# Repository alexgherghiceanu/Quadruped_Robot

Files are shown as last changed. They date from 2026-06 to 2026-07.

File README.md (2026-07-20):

# Quadruped Robot
 
A Bluetooth-controlled spider robot powered by an STM32 microcontroller and written in Rust.
 
| | |
|---|---|
| **Author** | Alexandru-Bogdan Gherghiceanu |
| **University** | Politehnica București — Faculty of Automatic Control and Computer Science |
| **Course** | Microprocessor Architecture (PM), 2026 |
| **Project page** | [embedded-rust-101.wyliodrin.com](https://embedded-rust-101.wyliodrin.com/docs/acs_cc/project/2026/agherghiceanu) |
 
---
 
## Description
 
This project is a Bluetooth-controlled quadruped (spider) robot that pairs with your phone or tablet over BLE. Once connected, you can control its speed and direction of travel, and issue special commands such as making it wave. The robot uses 8 servomotors to produce smooth, natural movement.
 
## Motivation
 
A long-standing interest in robotics, combined with years of following Boston Dynamics' work, made a quadruped robot a natural project choice. After watching *Project Hail Mary*, a spider form factor felt like the perfect fit. The chassis is a modified version of the open-source [Sesame spider robot](https://www.doriantodd.com/sesame), adapted to accommodate the chosen components.
 
---
 
## Architecture
 
The system is organized into the following software modules running on the STM32:
 
```
Android/iOS Device
        │  (BLE)
        ▼
  HM-10 Bluetooth Module
        │  (UART / Serial)
        ▼
  Bluetooth Handler Module   ← parses commands (e.g. 'F', 'L', 'W')
        │
        ▼
  Motion Planner Module      ← determines target pose / leg positions (X, Y, Z)
        │
        ▼
  Kinematics Engine (IK)     ← converts positions to servo angles
        │
        ▼
  I2C Controller Module
        │  (I2C)
        ▼
  PCA9685 Servo Driver       ← generates PWM signals
        │
        ▼
  Servomotors x8
```
 
---
 
## Hardware
 
The brain of the robot is the **STM32 Nucleo-U545RE-Q** microcontroller. It receives Bluetooth commands via the HM-10 module (UART), computes the required servo positions, and sends them to a **PCA9685** 16-channel PWM driver over I2C. The driver then actuates the 8 **MG90S** servomotors (2 per leg). Power comes from a **7.4V 1000mAh 2S LiPo** battery, stepped down to the appropriate voltage for the logic and servos via an **XL4015** buck converter.

## Build Progress & Media

A look at the robot from early assembly to a working walking gait.

### Photos
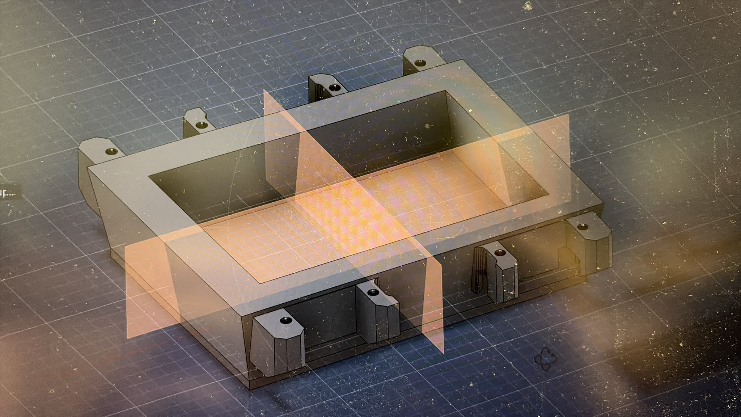
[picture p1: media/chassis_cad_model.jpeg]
CAD model of the chassis


| | |
|---|---|
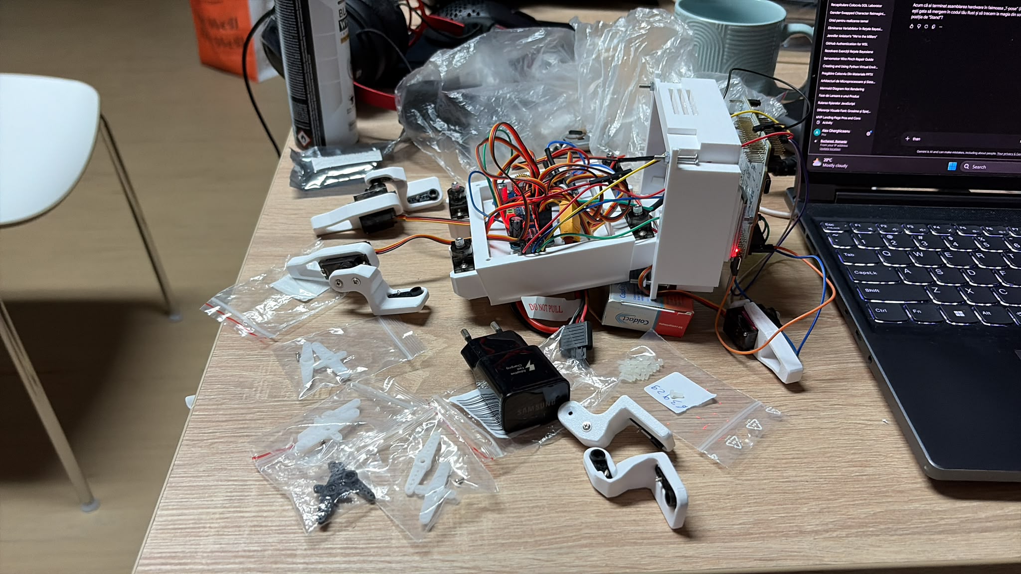
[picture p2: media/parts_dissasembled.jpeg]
Parts before assembly
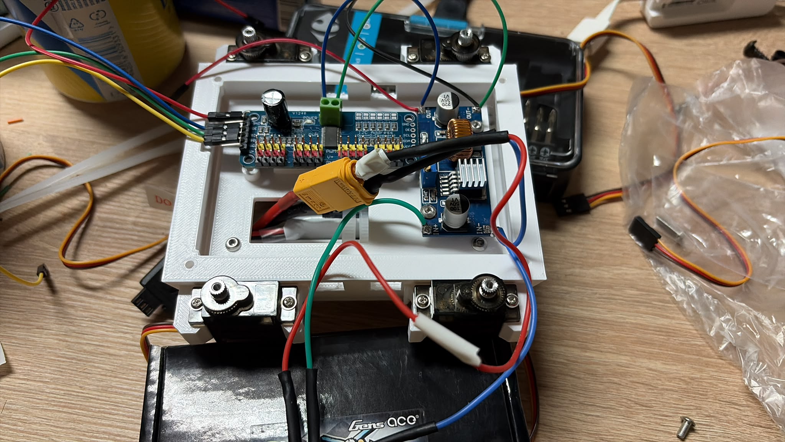
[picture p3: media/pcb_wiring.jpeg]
PCB and wiring
|  |  |
| Servos and parts before assembly | PCA9685 driver + power wiring |

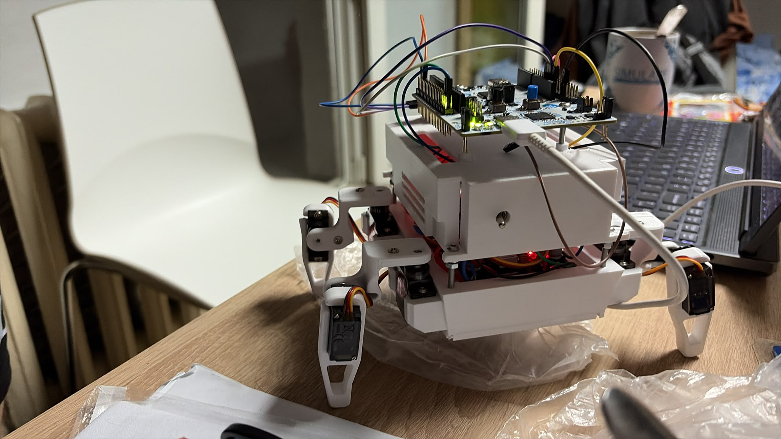
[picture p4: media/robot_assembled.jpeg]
Assembled robot


*The robot fully assembled, with the STM32 board mounted on top.*

### Demo

Walking demo
 
### Bill of Materials
 
| Component | Role | Price (RON) |
|---|---|---|
| STM32 Nucleo-U545RE-Q | Main microcontroller | ~120.00 |
| Servomotor MG90S (x8) | Leg actuation | 19.34 ea. |
| PCA9685 I2C 16-CH Servo Driver | Servo PWM interface | 27.27 |
| XL4015 Buck Converter (8-36V, 5A) | Voltage step-down | 9.96 |
| KCD-1 On/Off Switch | Power switch | 1.85 |
| HM-10 Bluetooth 4.0 Module | BLE communication | 29.99 |
| Electrolytic Capacitor 1000 uF 50V | Voltage buffering | 1.49 |
| 1K Ohm 0.25W Resistor | Signal conditioning | 0.10 |
| Undervoltage Battery Alarm | Low battery warning | 7.99 |
| B3 20W LiPo Charger (2S/3S) | Battery charging | 29.90 |
| Gens Ace 1000mAh 7.4V 30C 2S LiPo (XT60) | Main power source | 58.20 |
| XT60 Connector Set | Battery connection | 8.82 |
| Dupont F-F wires x10 (20cm) | Internal wiring | 2.67 |
| Dupont M-F wires x40 (20cm) | Internal wiring | 19.72 |
 
---
 
## Software
 
The firmware is written in **Rust** using the [Embassy](https://github.com/embassy-rs/embassy) async embedded framework.
 
| Library / Tool | Description | Usage |
|---|---|---|
| `embassy-stm32` | STM32 HAL | Controls board pins; drives PCA9685 via I2C and HM-10 via UART |
| `embassy-executor` | Async executor | Runs the main task loop, processes BLE commands, updates motor angles |
| `embassy-time` | Timekeeping & delays | Controls animation frame timing for walking gait; handles BLE read timeouts |
| `defmt` + `defmt-rtt` | Logging framework | Streams debug info and state changes to a connected laptop terminal |
| `panic-probe` | Panic handler | Captures crashes and prints backtraces for easier debugging |
| `probe-rs` | Flash & debug tool | Compiles, flashes, and runs firmware on the STM32 via `cargo run` |
 
### Building & Flashing
 
Requires a Rust toolchain with the `thumbv8m.main-none-eabihf` target and `probe-rs` installed.
 
```bash
# Add the target (once)
rustup target add thumbv8m.main-none-eabihf
 
# Build and flash
cargo run --release
```
 
---

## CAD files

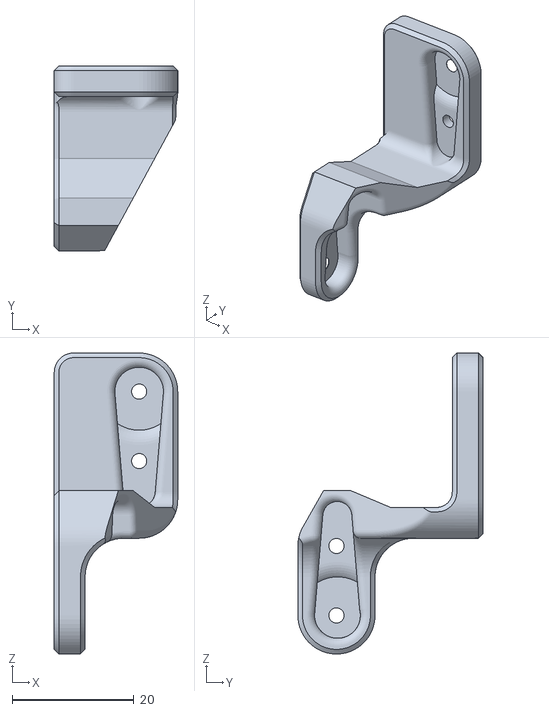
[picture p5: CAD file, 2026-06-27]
hardware/3D Files/R2-v117.stl
20.3 x 30.5 x 49.5

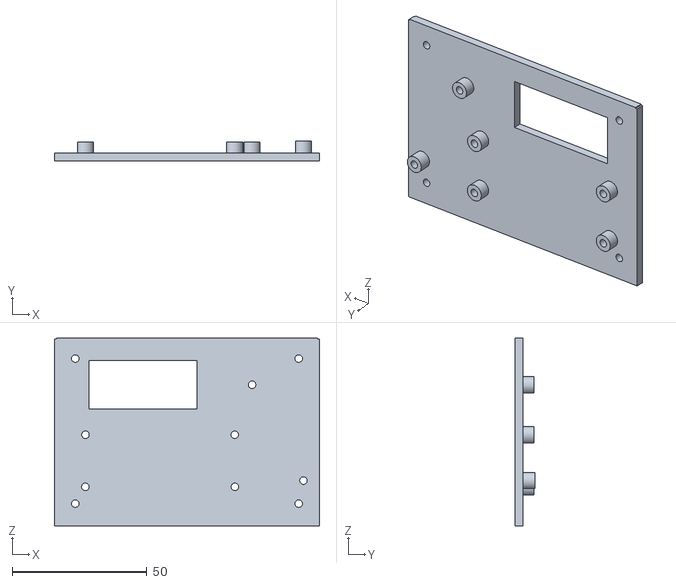
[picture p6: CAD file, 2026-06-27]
hardware/3D Files/cadru_intern_V3.stl
98.2 x 7.50 x 69.5

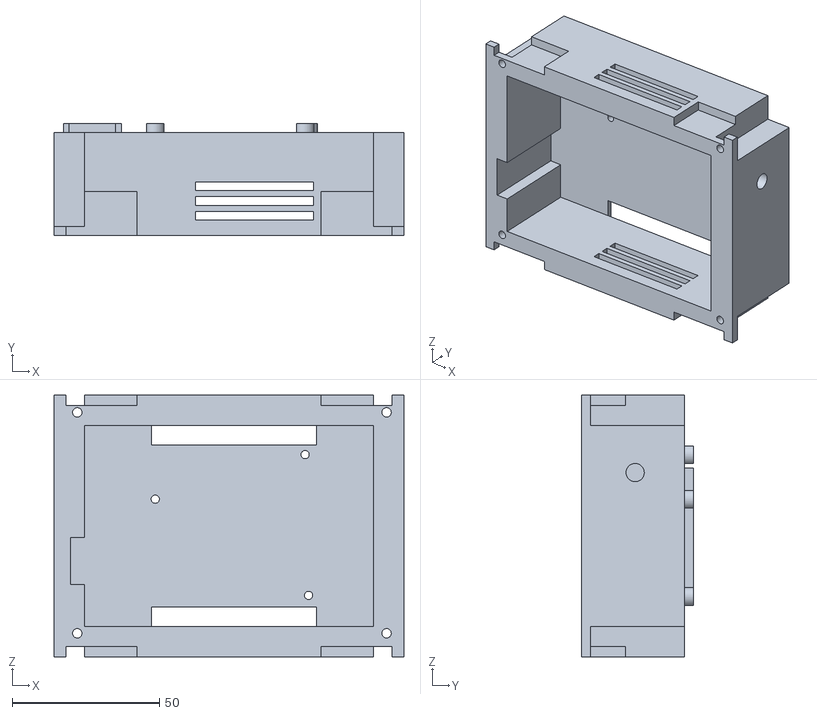
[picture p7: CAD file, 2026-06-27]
hardware/3D Files/cadru_nucleo+hm10.stl
118.8 x 38.0 x 88.8

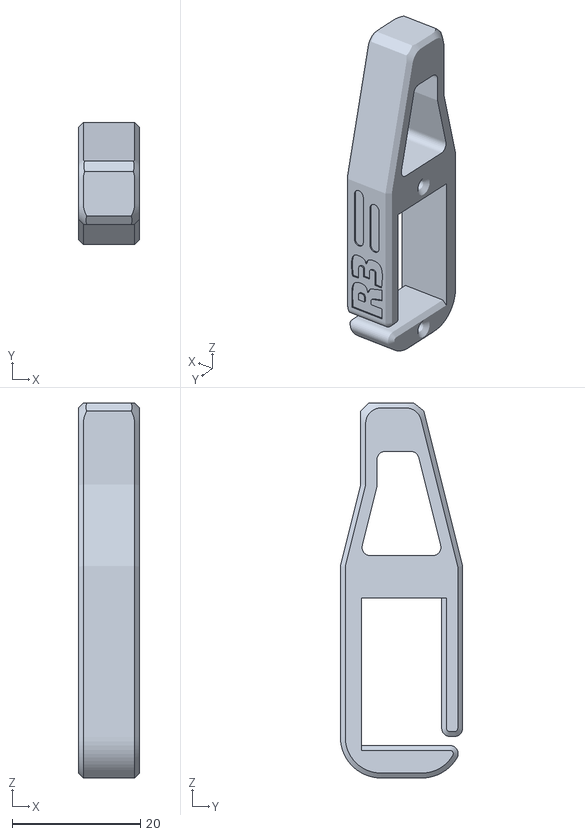
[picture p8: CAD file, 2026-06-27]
hardware/3D Files/R3-v117.stl
9.53 x 19.0 x 58.4

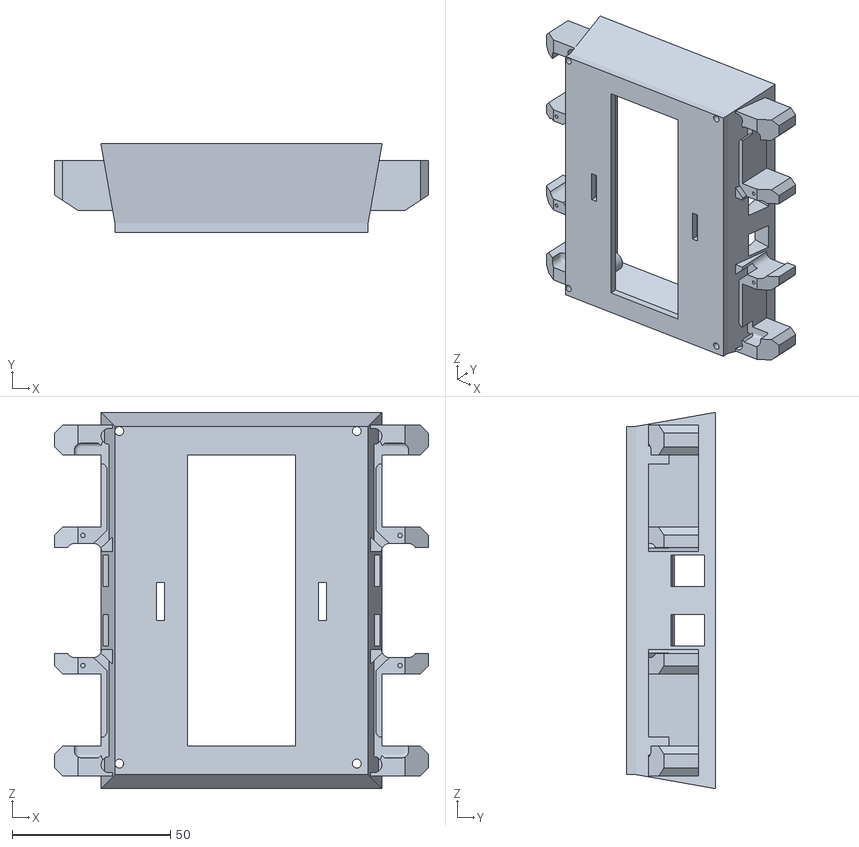
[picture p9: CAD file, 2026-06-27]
hardware/3D Files/baseplate_V2.stl
118.1 x 28.0 x 118.8

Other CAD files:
hardware/3D Files/L4-v117.stl
hardware/3D Files/L3-v117.stl
hardware/3D Files/L1-v117.stl
hardware/3D Files/L2-v117.stl
hardware/3D Files/R1-v117.stl
hardware/3D Files/R4-v117.stl

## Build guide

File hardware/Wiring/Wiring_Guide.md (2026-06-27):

## Wiring Guide
 
#### Power
 
The LiPo battery connects through the  on/off switch to the XL4015 buck converter `IN+` / `IN-`. Set the converter output to **5V** before connecting anything downstream. From the converter `OUT+` / `OUT-`, run power to two destinations: the **PCA9685** `V+` and `GND` rails (servo power), and the **STM32 Nucleo** `+5V` and `GND` pins.
 
#### HM-10 Bluetooth Module — UART
 
| HM-10 pin | STM32 pin |
|---|---|
| TXD (BT_RX net) | PA9 (BT_RX) |
| RXD (BT_TX net) | PA10 (BT_TX) |
| VCC | +5V |
| GND | GND |
 
Note the net labels cross as expected: the module's TX feeds the MCU's RX pin and vice versa.
 
#### PCA9685 Servo Driver  — I2C
 
| PCA9685 pin | STM32 pin |
|---|---|
| SCL | PB6 (I2C_SCL) |
| SDA | PB7 (I2C_SDA) |
| GND | GND |
| OE | GND (tie low to enable outputs) |
| VCC | +5V |
| V+ | +5V from buck converter |
 
VCC powers the PCA9685 logic and comes from the STM32 board and runs at 3.3V. V+ powers the servo rail runs at 5V here from the buck converter output.
 
#### Servomotors — PCA9685 outputs 
 
The 8 servos connect to the PCA9685. Each servo's signal wire maps to a PWM channel net.
 
Each servo connector is 3-pin: signal (PWM), VCC (+5V), GND. Power and ground for all servos come from the PCA9685 V+ and GND rails.

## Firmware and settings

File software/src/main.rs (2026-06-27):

#![no_std]
#![no_main]

use defmt::info;
use defmt_rtt as _;
use panic_probe as _;

use embassy_executor::Spawner;
use embassy_stm32::{bind_interrupts, peripherals, usart};
use embassy_stm32::i2c::{I2c, Config as I2cConfig};
use embassy_stm32::usart::{BufferedUart, Config as UartConfig};
use embassy_stm32::time::Hertz;
use embassy_time::{Duration, Timer, with_timeout};
use embedded_io_async::Read;

bind_interrupts!(struct Irqs {
    LPUART1 => usart::BufferedInterruptHandler<peripherals::LPUART1>;
});

#[derive(PartialEq)]
enum State {
    Stand,
    Forward,
    Backward,
    Left,
    Right,
    Debug,
    Wave
}

fn get_servo_buffer(angles: &[u8; 8]) -> [u8; 61] {
    let mut buf = [0u8; 61];
    buf[0] = 0x06; 

    const MIN_PULSE_US: u32 = 732;
    const MAX_PULSE_US: u32 = 2929;
    const PERIOD_US: u32 = 20000;

    let pca_pins: [usize; 8] = [0, 2, 4, 7, 8, 10, 12, 14];

    for i in 0..8 {
        let pin = pca_pins[i];
        let offset = 1 + pin * 4;
        
        let pulse = angles[i] as u32 * (MAX_PULSE_US - MIN_PULSE_US) / 180 + MIN_PULSE_US;
        let tick = ((pulse * 4096) / PERIOD_US) as u16;

        buf[offset] = 0;
        buf[offset + 1] = 0;
        buf[offset + 2] = (tick & 0xFF) as u8;
        buf[offset + 3] = (tick >> 8) as u8;
    }
    
    buf
}

#[embassy_executor::main]
async fn main(_spawner: Spawner) {
    let p = embassy_stm32::init(Default::default());
    

    info!("--- PLACA A PORNIT! INCEP INITIALIZAREA I2C ---");


    let mut i2c_config = I2cConfig::default();
    i2c_config.frequency = Hertz(100_000);
    let mut i2c = I2c::new_blocking(p.I2C1, p.PB6, p.PB7, i2c_config);
    let address = 0x40;

    info!("Pornire PCA9685...");
    let _ = i2c.blocking_write(address, &[0x00, 0x10]);
    let _ = i2c.blocking_write(address, &[0xFE, 121]);
    let _ = i2c.blocking_write(address, &[0x00, 0x20]);
    Timer::after_millis(10).await;

    let mut uart_config = UartConfig::default();
    uart_config.baudrate = 9600;
    
    static mut TX_STORAGE: [u8; 16] = [0; 16];
    static mut RX_STORAGE: [u8; 64] = [0; 64];

    let tx_buffer = unsafe { &mut *(&raw mut TX_STORAGE) };
    let rx_buffer = unsafe { &mut *(&raw mut RX_STORAGE) };
    
    let mut serial = BufferedUart::new(
        p.LPUART1, 
        p.PA3, // RX
        p.PA2, // TX
        tx_buffer, 
        rx_buffer, 
        Irqs, 
        uart_config
    ).unwrap();

    let mut state = State::Debug;
    let mut frame: usize = 0;
    let mut b = [0u8; 1]; 

    info!("Comenzi: W(Fata), S(Spate), A(Stanga), D(Dreapta), Q(Debug Montaj), E(Wave), T(Stand)");

    loop {
        if let Ok(Ok(_)) = with_timeout(Duration::from_millis(20), serial.read(&mut b)).await {
            let cmd = b[0] as char;
            match cmd {
                'W' | 'w' => { state = State::Forward; frame = 0; info!("FATA "); }
                'S' | 's' => { state = State::Backward; frame = 0; info!("SPATE "); }
                'A' | 'a' => { state = State::Left; frame = 0; info!("STANGA "); }
                'D' | 'd' => { state = State::Right; frame = 0; info!("DREAPTA "); }
                'Q' | 'q' => { state = State::Debug; frame = 0; info!("Debug Montaj (Toate la 90)"); }
                'E' | 'e' => { state = State::Wave; frame = 0; info!("Wave"); }
                'T' | 't' => { state = State::Stand; frame = 0; info!("Sta in picioare!"); }
                _ => {}
            }
        }

        match state {
            State::Stand => {
                                        // L1 ,L3, L2 ,L4, R1, R3, R2, R4
               let stand_pose = [90, 45,  90, 135, 90, 135,  90, 45]; 
                
                let buf = get_servo_buffer(&stand_pose);
                let _ = i2c.blocking_write(address, &buf);
            }
            State::Forward => {
                let frames = [
                    [110, 80,   70, 135,   110, 135,   110, 45],
                    [110, 45,   70, 135,   110, 135,   110, 45],

                    [110, 45,   70, 135,   110, 135,   70, 80],
                    [110, 45,   70, 135,   110, 135,   70, 45],

                    [110, 45,   70, 135,   70, 100,    70, 45],
                    [110, 45,   70, 135,   70, 135,    70, 45],

                    [110, 45,   110, 100,  70, 135,    70, 45],
                    [110, 45,   110, 135,  70, 135,    70, 45],

                    [70, 45,    70, 135,   110, 135,   110, 45],
                ];
                let buf = get_servo_buffer(&frames[frame]);
                let _ = i2c.blocking_write(address, &buf);
                
                frame += 1;
                if frame >= frames.len() {
                    frame = 0; 
                }
            }
            State::Backward => {
                let frames = [
                    [70, 80,   110, 135,  70, 135,   70, 45],
                    [70, 45,   110, 135,  70, 135,   70, 45],

                    [70, 45,   110, 135,  70, 135,   110, 80],
                    [70, 45,   110, 135,  70, 135,   110, 45],

                    [70, 45,   110, 135,  110, 100,  110, 45],
                    [70, 45,   110, 135,  110, 135,  110, 45],

                    [70, 45,   70, 100,   110, 135,  110, 45],
                    [70, 45,   70, 135,   110, 135,  110, 45],

                    [110, 45,  110, 135,  70, 135,   70, 45],
                ];
                let buf = get_servo_buffer(&frames[frame]);
                let _ = i2c.blocking_write(address, &buf);
                
                frame += 1;
                if frame >= frames.len() {
                    frame = 0; 
                }
            }
            State::Left => {
                let frames = [
                    [70, 80,   110, 135,  110, 135,  110, 45], 
                    [70, 45,   110, 135,  110, 135,  110, 45], 
                    
                    [70, 45,   110, 135,  110, 135,  70, 80], 
                    [70, 45,   110, 135,  110, 135,  70, 45], 
                    
                    [70, 45,   110, 135,  70, 100,   70, 45], 
                    [70, 45,   110, 135,  70, 135,   70, 45], 
                    
                    [70, 45,   70, 100,   70, 135,   70, 45], 
                    [70, 45,   70, 135,   70, 135,   70, 45], 
                    
                    [110, 45,  110, 135,  110, 135,  110, 45],
                ];
                let buf = get_servo_buffer(&frames[frame]);
                let _ = i2c.blocking_write(address, &buf);
                
                frame += 1;
                if frame >= frames.len() {
                    frame = 0;
                }
            }
            State::Right => {
                let frames = [
                    [110, 80,   70, 135,  70, 135,  70, 45], 
                    [110, 45,   70, 135,  70, 135,  70, 45], 
                    
                    [110, 45,   70, 135,  70, 135,  110, 80], 
                    [110, 45,   70, 135,  70, 135,  110, 45], 
                    
                    [110, 45,   70, 135,  110, 100, 110, 45], 
                    [110, 45,   70, 135,  110, 135, 110, 45], 
                    
                    [110, 45,   110, 100, 110, 135, 110, 45], 
                    [110, 45,   110, 135, 110, 135, 110, 45], 
                    
                    [70, 45,    70, 135,  70, 135,  70, 45],
                ];
                let buf = get_servo_buffer(&frames[frame]);
                let _ = i2c.blocking_write(address, &buf);
                
                frame += 1;
                if frame >= frames.len() {
                    frame = 0;
                }
            }
            State::Debug => {
                let buf = get_servo_buffer(&[90, 90, 90, 90,  90, 90, 90, 90]);
                let _ = i2c.blocking_write(address, &buf);
            }
            State::Wave => {
                let frames = [
                    [90, 125,   90, 135,   90, 135,   90, 65],

                    [90, 90,  90, 135,   90, 135,   90, 65],
                    
                    [90, 55,   90, 135,   90, 135,   90, 65],
                    
                    [90, 90,   90, 135,   90, 135,   90, 65],
                ];
                
                let buf = get_servo_buffer(&frames[frame]);
                let _ = i2c.blocking_write(address, &buf);
                
                frame += 1;
                if frame >= frames.len() { frame = 0; }
            }
        }

        Timer::after_millis(150).await;
    }
}

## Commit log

2026-06-27 Create Assembly Guide
2026-06-27 Expand README with project details and instructions
    Added detailed project description, motivation, architecture, hardware, bill of materials, software libraries, and building instructions.
2026-06-27 Refactor README.md for better organization and clarity
    Reformatted README.md to improve structure and clarity, added tables for author, university, course, project page, bill of materials, and software libraries.
2026-06-27 Create Wiring Guide
2026-06-27 Add wiring guide for hardware connections
    Added detailed wiring instructions for power connections, HM-10 Bluetooth module, PCA9685 servo driver, and servomotors.
2026-06-27 Add wiring guide for hardware components
    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
2026-06-27 Refine Wiring Guide for clarity and conciseness
    Removed redundant text in the wiring guide and clarified connections.
2026-06-27 Revise Wiring Guide for Power and Components
    Updated wiring guide for clarity and accuracy regarding power connections and component specifications.
2026-07-20 Update project description in README.md
    Removed mention of inverse kinematics and number of servomotors.
